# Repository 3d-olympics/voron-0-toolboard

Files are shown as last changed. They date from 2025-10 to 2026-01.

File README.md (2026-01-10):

# USB toolhead board for Voron 0.2

This board replaces the strain relief part at the back of the Voron 0.2's toolhead. It receives 24V through the a USB-C cable - a companion board/connector allows this power voltage to be injected between your RPi and the USB-C cable to this toolboard.
This is non-standard and not really advisable, so proceed at your own risk!



https://youtu.be/3sF8bKx-5_M

## Features
* ADXL345 accelerometer, with interrupt pin connected for use as a "probe"
* TMC2209 driver for extruder motor
* STM32F042G6U6TR, 28-pin microcontroller for running Klipper
* USB-C connector with strain relief
* Connectors for heater and two thermistors
* Connector for a probe or other device e.g. LEDs
* Connectors for hotend fan and two cooling fans
* 5V buck regulator - hotend and cooling fans can separately be supplied with 5 or 24V

The project is developed in KiCad, and that's what the project files are for.

If there's any interest I'll provide some more material like gerber and BOM files.



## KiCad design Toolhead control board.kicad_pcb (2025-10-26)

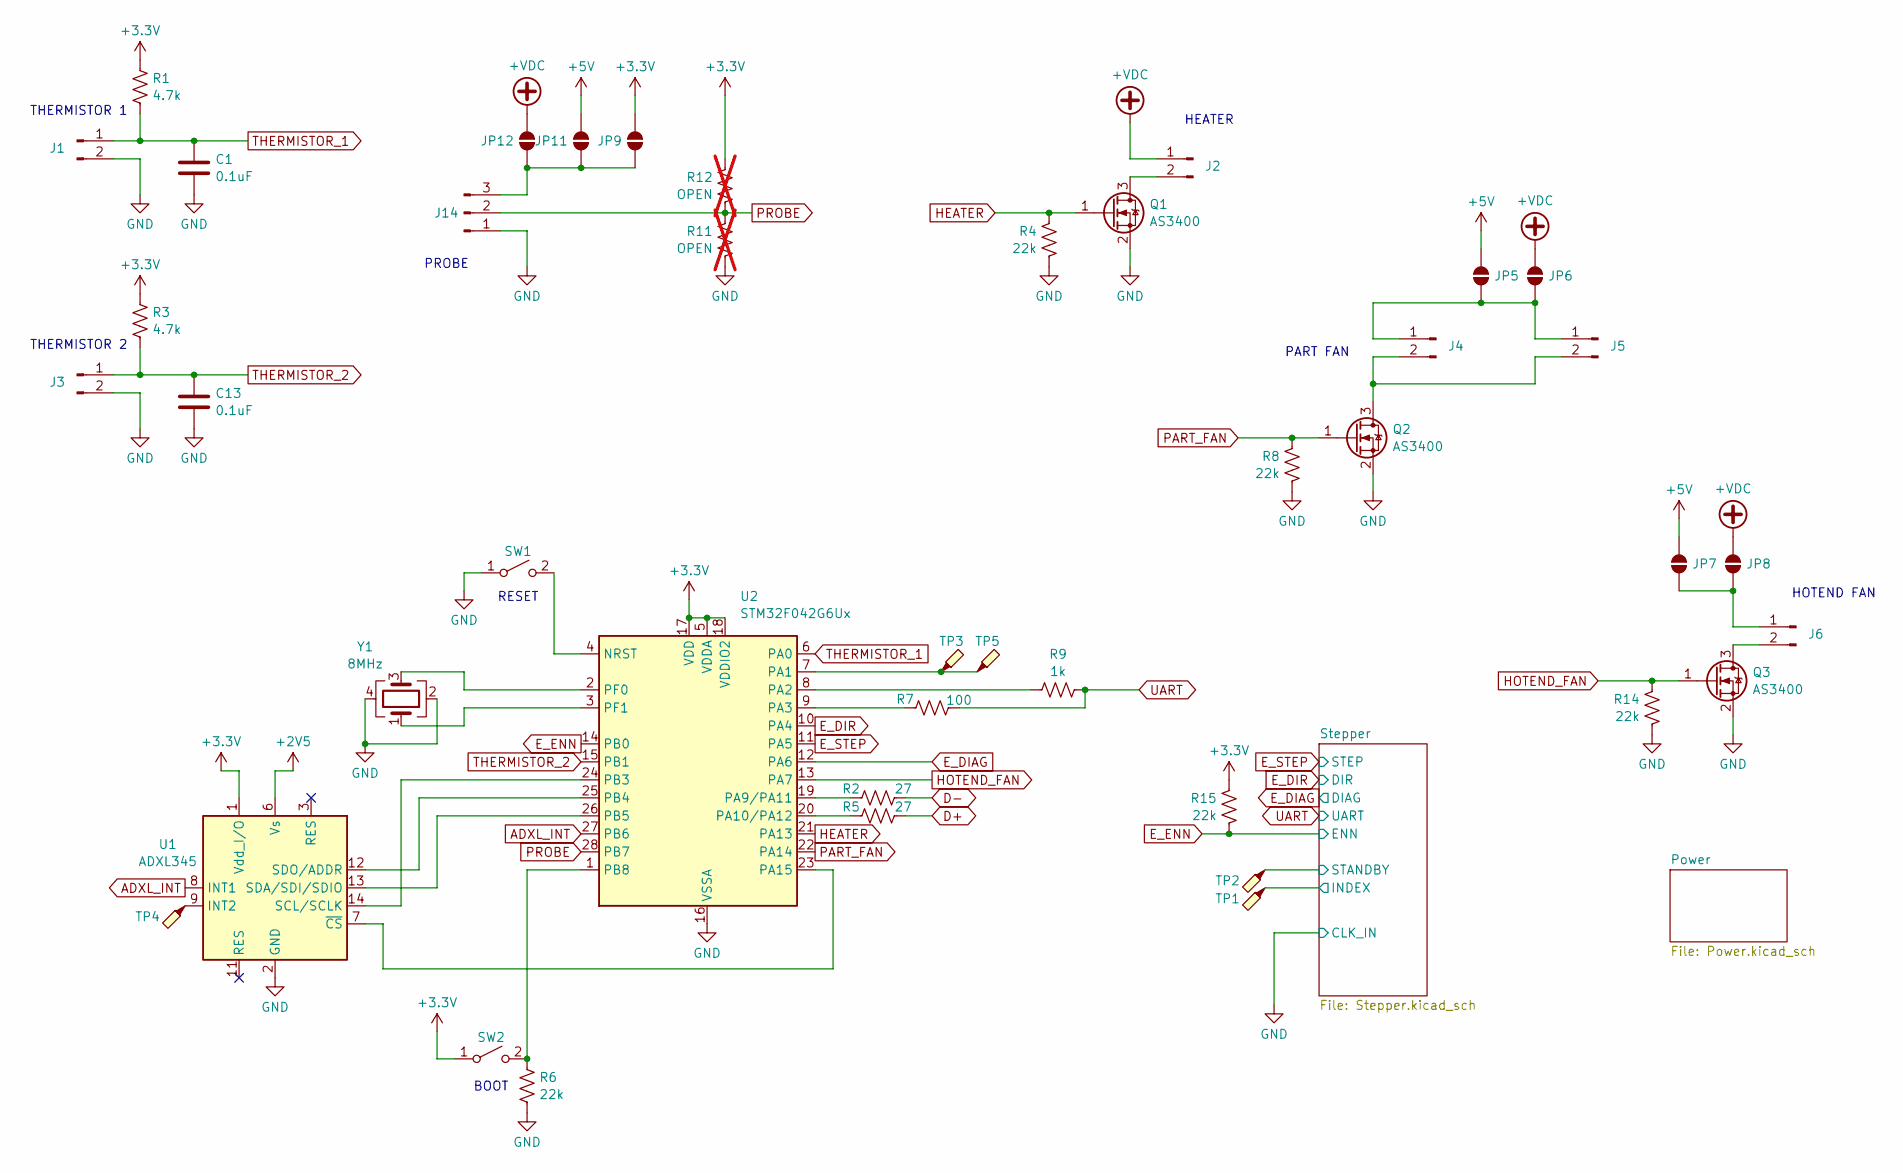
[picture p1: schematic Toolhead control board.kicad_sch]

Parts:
C1, C13: 0.1uF; C_0603_1608Metric
J1, J3, J4, J5, J6: Conn_01x02_Pin; JST_XH_B2B-XH-A_1x02_P2.50mm_Vertical
J2: Conn_01x02_Pin; TerminalBlock_Phoenix_PT-1,5-2-3.5-H_1x02_P3.50mm_Horizontal
J14: Conn_01x04_Male; JST_XH_S3B-XH-A-1_1x03_P2.50mm_Horizontal
JP5, JP6, JP7, JP8, JP9, JP11, JP12: SolderJumper_2_Open; SolderJumper-2_P1.3mm_Open_TrianglePad1.0x1.5mm
Q1, Q2, Q3: AS3400; SOT-23
R1, R3: 4.7k; R_0603_1608Metric
R2, R5: 27; R_0603_1608Metric
R4, R6, R8, R14, R15: 22k; R_0603_1608Metric
R7: 100; R_0603_1608Metric
R9: 1k; R_0603_1608Metric
R11, R12: OPEN; R_0603_1608Metric; not fitted
SW1, SW2: SW_SPST; SW_SPST_B3U-1000P
TP1, TP2, TP3, TP4, TP5: TestPoint_Probe; TestPoint_Pad_D1.0mm
U1: ADXL345; LGA-14_3x5mm_P0.8mm_LayoutBorder1x6y
U2: STM32F042G6Ux; QFN-28_4x4mm_P0.5mm
Y1: 8MHz; Crystal_SMD_3225-4Pin_3.2x2.5mm

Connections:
+2V5: U1.6 (Vs); also elsewhere on the board
+3.3V: JP9.2 (B), R1.1, R3.1, R12.1, R15.1, SW2.1 (A), U1.1 (Vdd_I/O), U2.5 (VDDA), U2.17 (VDD), U2.18 (VDDIO2); also elsewhere on the board
+5V: JP5.2 (B), JP7.2 (B), JP11.2 (B); also elsewhere on the board
+VDC: J2.1, JP6.2 (B), JP8.2 (B), JP12.2 (B); also elsewhere on the board
/Stepper/INDEX: TP1.1; also elsewhere on the board
/Stepper/STANDBY: TP2.1; also elsewhere on the board
ADXL_INT: U1.8 (INT1), U2.27 (PB6)
D+: R5.2; also elsewhere on the board
D-: R2.2; also elsewhere on the board
E_DIAG: U2.12 (PA6); also elsewhere on the board
E_DIR: U2.10 (PA4); also elsewhere on the board
E_ENN: R15.2, U2.14 (PB0); also elsewhere on the board
E_STEP: U2.11 (PA5); also elsewhere on the board
GND: C1.2, C13.2, J1.2, J3.2, J14.1, Q1.2 (S), Q2.2 (S), Q3.2 (S), R4.2, R6.2, R8.2, R11.2, R14.2, SW1.1 (A), U1.2 (GND), U1.4 (GND), U1.5 (GND), U2.16 (VSSA), Y1.2, Y1.4; also elsewhere on the board
HEATER: Q1.1 (G), R4.1, U2.21 (PA13)
HOTEND_FAN: Q3.1 (G), R14.1, U2.13 (PA7)
unnamed 18: J2.2, Q1.3 (D); also elsewhere on the board
unnamed: J4.1, J5.1, JP5.1 (A), JP6.1 (A)
unnamed: J4.2, J5.2, Q2.3 (D)
unnamed: J6.1, JP7.1 (A), JP8.1 (A)
unnamed: J6.2, Q3.3 (D)
unnamed: J14.3, JP9.1 (A), JP11.1 (A), JP12.1 (A)
unnamed: SW1.2 (B), U2.4 (NRST)
unnamed: R6.1, SW2.2 (B), U2.1 (PB8)
unnamed: TP4.1, U1.9 (INT2)
unnamed: U1.14 (SCL/SCLK), U2.24 (PB3)
unnamed: U1.13 (SDA/SDI/SDIO), U2.26 (PB5)
unnamed: U1.12 (SDO/ADDR), U2.25 (PB4)
unnamed: U1.7 (~CS), U2.23 (PA15)
unnamed: TP3.1, TP5.1, U2.7 (PA1)
unnamed: R9.1, U2.8 (PA2)
unnamed: R7.1, U2.9 (PA3)
unnamed: R2.1, U2.19 (PA9/PA11)
unnamed: R5.1, U2.20 (PA10/PA12)
unnamed: U2.2 (PF0), Y1.3
unnamed: U2.3 (PF1), Y1.1
PART_FAN: Q2.1 (G), R8.1, U2.22 (PA14)
PROBE: J14.2, R11.1, R12.2, U2.28 (PB7)
THERMISTOR_1: C1.1, J1.1, R1.2, U2.6 (PA0)
THERMISTOR_2: C13.1, J3.1, R3.2, U2.15 (PB1)
UART: R7.2, R9.2; also elsewhere on the board

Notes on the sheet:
PROBE
HOTEND FAN
PART FAN
THERMISTOR 1
THERMISTOR 2
BOOT
HEATER
RESET

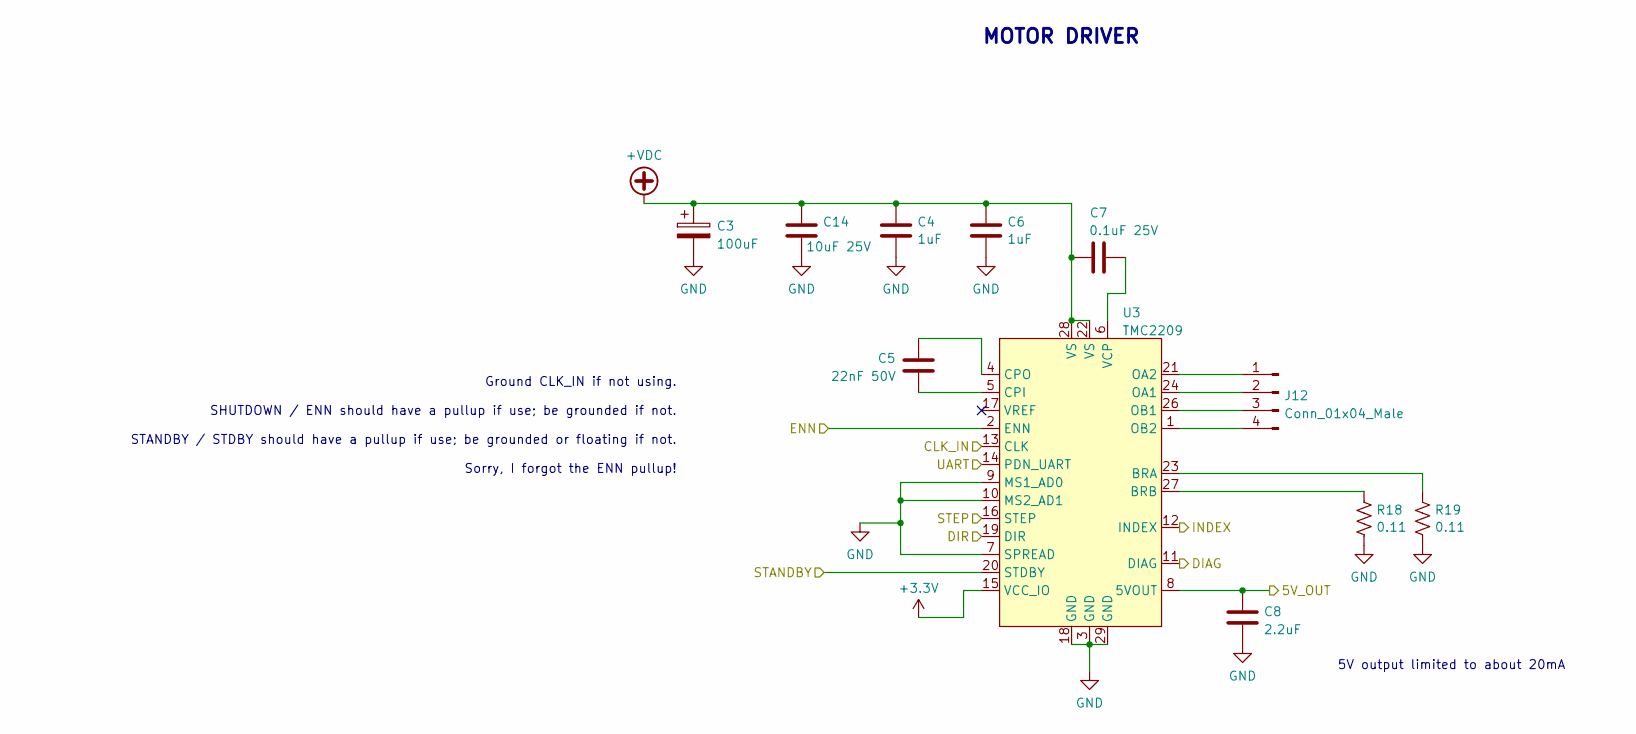
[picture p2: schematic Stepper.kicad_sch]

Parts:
C3: 100uF; CP_Radial_D6.3mm_P2.50mm
C4, C6: 1uF; C_0603_1608Metric
C5: 22nF 50V; C_0603_1608Metric
C7: 0.1uF 25V; C_0603_1608Metric
C8: 2.2uF; C_0603_1608Metric
C14: 10uF 25V; C_0805_2012Metric
J12: Conn_01x04_Male; JST_XH_S4B-XH-A-1_1x04_P2.50mm_Horizontal
R18, R19: 0.11; R_1206_3216Metric
U3: TMC2209; QFN-28-1EP_5x5mm_P0.5mm_EP3.35x3.35mm

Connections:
+3.3V: U3.15 (VCC_IO); also elsewhere on the board
+VDC: C3.1, C4.1, C6.1, C7.1, C14.1, U3.22 (VS), U3.28 (VS); also elsewhere on the board
/Stepper/5V_OUT: C8.1, U3.8 (5VOUT)
/Stepper/INDEX: U3.12 (INDEX); also elsewhere on the board
/Stepper/STANDBY: U3.20 (STDBY); also elsewhere on the board
E_DIAG: U3.11 (DIAG); also elsewhere on the board
E_DIR: U3.19 (DIR); also elsewhere on the board
E_ENN: U3.2 (ENN); also elsewhere on the board
E_STEP: U3.16 (STEP); also elsewhere on the board
GND: C3.2, C4.2, C6.2, C8.2, C14.2, R18.2, R19.2, U3.3 (GND), U3.7 (SPREAD), U3.9 (MS1_AD0), U3.10 (MS2_AD1), U3.13 (CLK), U3.18 (GND), U3.29 (GND); also elsewhere on the board
unnamed: J12.1, U3.21 (OA2)
unnamed: J12.2, U3.24 (OA1)
unnamed: J12.3, U3.26 (OB1)
unnamed: J12.4, U3.1 (OB2)
unnamed: R19.1, U3.23 (BRA)
unnamed: R18.1, U3.27 (BRB)
unnamed: C5.2, U3.5 (CPI)
unnamed: C5.1, U3.4 (CPO)
unnamed: C7.2, U3.6 (VCP)
UART: U3.14 (PDN_UART); also elsewhere on the board

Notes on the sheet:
5V output limited to about 20mA
MOTOR DRIVER
Ground CLK_IN if not using. SHUTDOWN / ENN should have a pullup if use; be grounded if not. STANDBY / STDBY should have a pullup if use; be grounded or floating if not. Sorry, I forgot the ENN pullup!

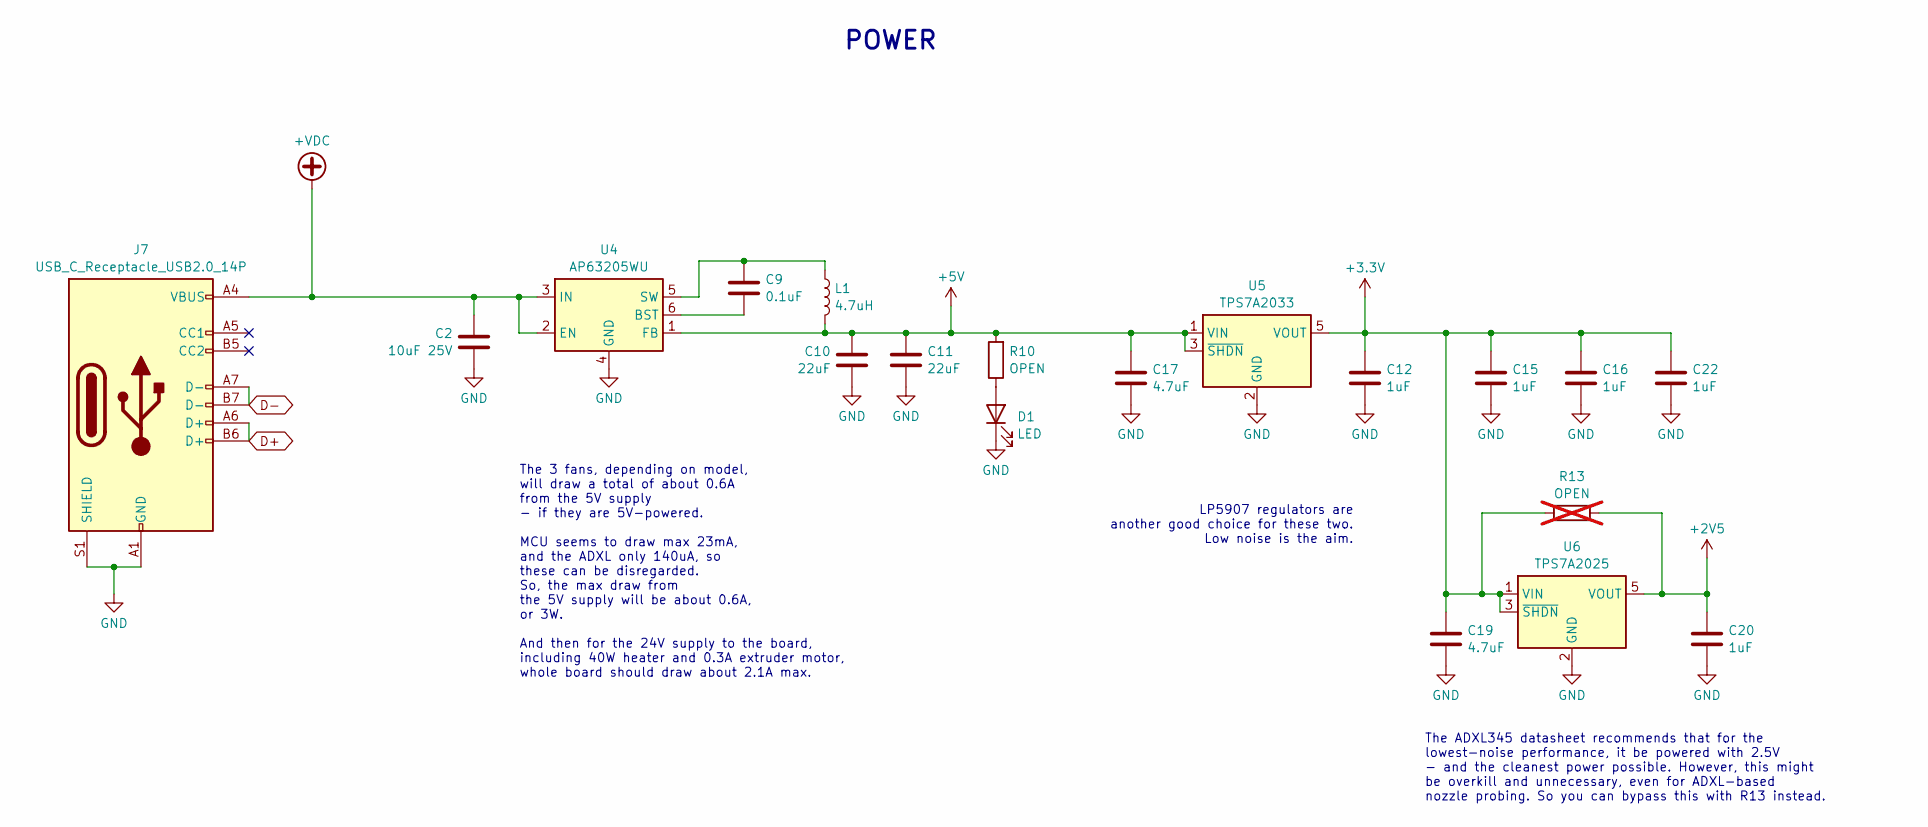
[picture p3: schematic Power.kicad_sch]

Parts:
C2: 10uF 25V; C_0805_2012Metric
C9: 0.1uF; C_0603_1608Metric
C10, C11: 22uF; C_0805_2012Metric
C12, C15, C16, C20, C22: 1uF; C_0603_1608Metric
C17, C19: 4.7uF; C_0805_2012Metric
D1: LED; LED_0603_1608Metric
J7: USB_C_Receptacle_USB2.0_14P; USB_C_Receptacle_GCT_USB4085
L1: 4.7uH; L_Taiyo-Yuden_MD-3030
R10: OPEN; R_0603_1608Metric
R13: OPEN; R_0603_1608Metric; not fitted
U4: AP63205WU; TSOT-23-6
U5: TPS7A2033; SOT-23-5
U6: TPS7A2025; SOT-23-5

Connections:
+2V5: C20.1, R13.2, U6.5 (VOUT); also elsewhere on the board
+3.3V: C12.1, C15.1, C16.1, C19.1, C22.1, R13.1, U5.5 (VOUT), U6.1 (VIN), U6.3 (~SHDN); also elsewhere on the board
+5V: C10.1, C11.1, C17.1, L1.2, R10.2, U4.1 (FB), U5.1 (VIN), U5.3 (~SHDN); also elsewhere on the board
+VDC: C2.1, J7.A4 (VBUS), J7.A9 (VBUS), J7.B4 (VBUS), J7.B9 (VBUS), U4.2 (EN), U4.3 (IN); also elsewhere on the board
D+: J7.A6 (D+), J7.B6 (D+); also elsewhere on the board
D-: J7.A7 (D-), J7.B7 (D-); also elsewhere on the board
GND: C2.2, C10.2, C11.2, C12.2, C15.2, C16.2, C17.2, C19.2, C20.2, C22.2, D1.1 (K), J7.A1 (GND), J7.A12 (GND), J7.B1 (GND), J7.B12 (GND), J7.S1 (SHIELD), U4.4 (GND), U5.2 (GND), U6.2 (GND); also elsewhere on the board
unnamed: D1.2 (A), R10.1
unnamed: C9.2, U4.6 (BST)
unnamed: C9.1, L1.1, U4.5 (SW)

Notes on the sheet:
The ADXL345 datasheet recommends that for the lowest-noise performance, it be powered with 2.5V - and the cleanest power possible. However, this might be overkill and unnecessary, even for ADXL-based nozzle probing. So you can bypass this with R13 instead.
POWER
LP5907 regulators are another good choice for these two. Low noise is the aim.
The 3 fans, depending on model, will draw a total of about 0.6A from the 5V supply - if they are 5V-powered. MCU seems to draw max 23mA, and the ADXL only 140uA, so these can be disregarded. So, the max draw from the 5V supply will be about 0.6A, or 3W. And then for the 24V supply to the board, inc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

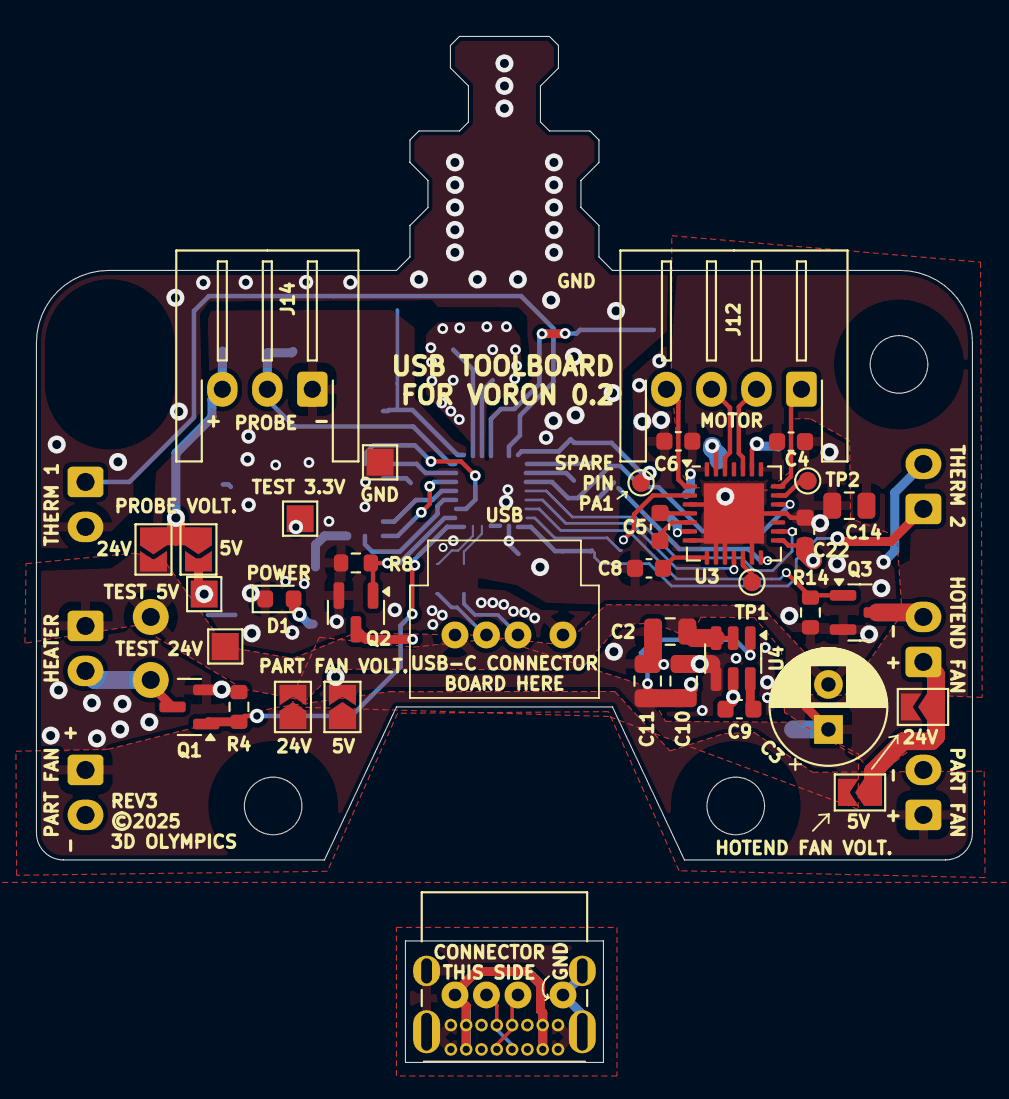
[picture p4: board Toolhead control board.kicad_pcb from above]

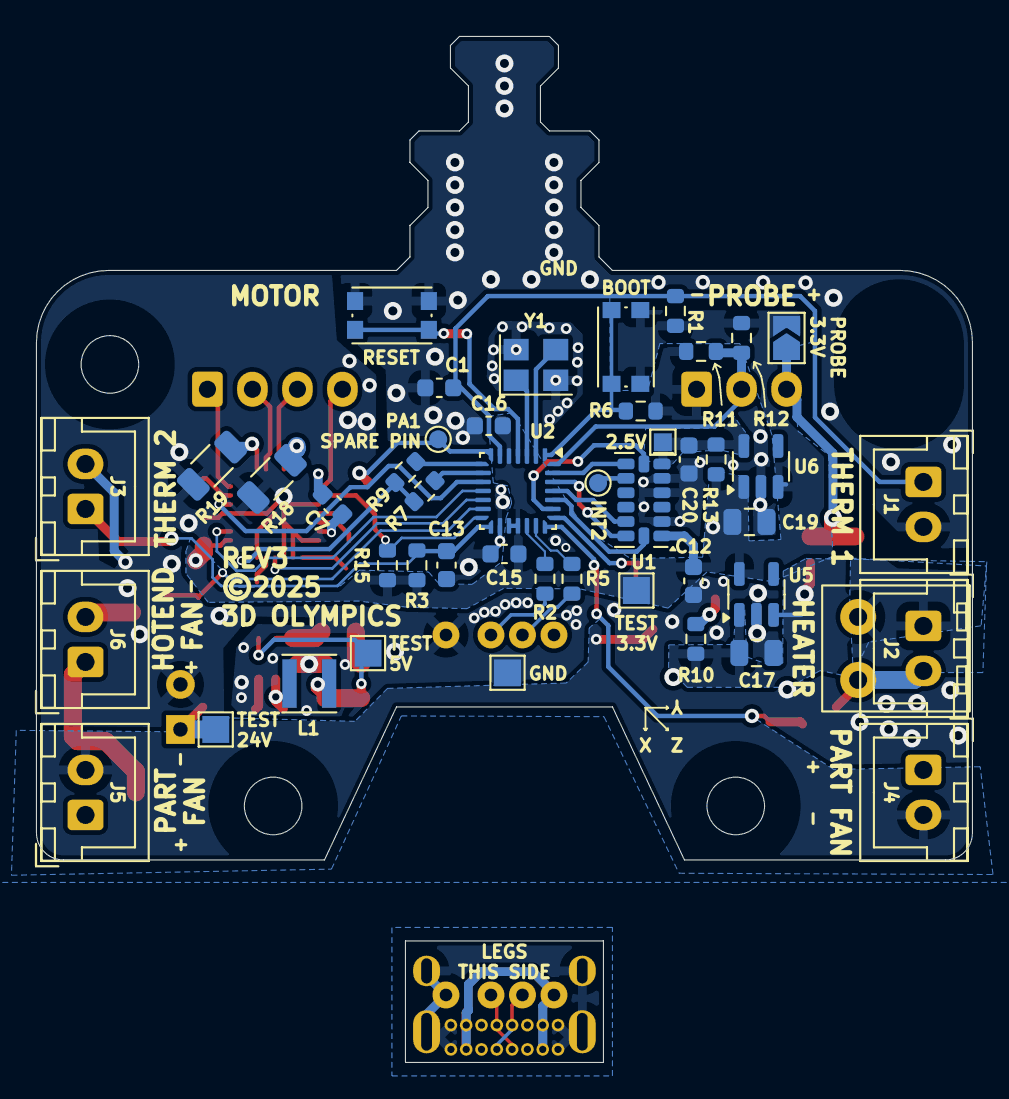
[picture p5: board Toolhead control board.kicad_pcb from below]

Board: 2 copper layers, 52.0 x 45.8 mm, 73 parts (41 on the bottom side), 54 nets.

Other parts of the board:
J2#2: Conn_01x02_Pin; JST_XH_B2B-XH-A_1x02_P2.50mm_Vertical

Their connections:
+VDC: J2#2.1; also elsewhere on the board
unnamed 18: J2#2.2; also elsewhere on the board

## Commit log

2025-09-25 Initial commit. Old version with programmer interface, no probe, etc
    [Power.kicad_sch, Stepper.kicad_sch, Toolhead control board.kicad_pcb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]
2025-09-30 Rev1. Uart interface
    [Power.kicad_sch, Stepper.kicad_sch, Toolhead control board.kicad_pcb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]
2025-10-02 Rev2 (USB) largely done
    [Power.kicad_sch, Toolhead control board.kicad_pcb, Toolhead control board.kicad_sch]
2025-10-22 Rev2, as ordered
    [Power.kicad_sch, Stepper.kicad_sch, Toolhead control board.kicad_pcb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]
2025-10-26 Rev3 (connectors on back, and with USB daughter board) - probably done
    [Power.kicad_sch, Stepper.kicad_sch, Toolhead control board.kicad_pcb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]
2026-01-06 Little changes while populating
    [Power.kicad_sch, Stepper.kicad_sch, Toolhead control board.kicad_sch]
2026-01-06 Oops I'd saved a test thing accidentally
    [Toolhead control board.kicad_sch]

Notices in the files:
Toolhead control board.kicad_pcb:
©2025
